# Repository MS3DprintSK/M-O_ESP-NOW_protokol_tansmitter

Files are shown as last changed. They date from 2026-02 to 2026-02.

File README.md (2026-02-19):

# M-O_ESP-NOW_protokol_tansmitter
Here you will find all the information about my way of controlling M-O from the Wall-e story. Don't look for the 3D model of M-O here! You will find it in the WALL-E Builders Club community files.

# M-O Control ESP NOW – Sedláček 🤖

This project utilizes the **ESP NOW** protocol for wireless robot control. The system is divided into a **Controller (Transmitter), Head, Eyes, and Body units**.

---

## 📑 Project Overview

- **Control Protocol:** Uses ESP NOW where eye displays process data as numbers **1–7** and display images accordingly.  
- **Head Unit:** Processes up/down movement (**0–180** from joystick) and controls the beacon.  
- **Body Unit:** Controls driving direction, speed, head rotation, and plays sounds.  
- **Security:** Communication is locked to specific MAC addresses to prevent accidental control of different robots.  

📄 **Full Documentation:**  
See the detailed manual here → [instruction.pdf](instruction.pdf)

---

## 🛠️ Hardware & Wiring

Detailed wiring diagrams can be found on **page 4** of the documentation.

### 🔌 Robot Wiring Diagram

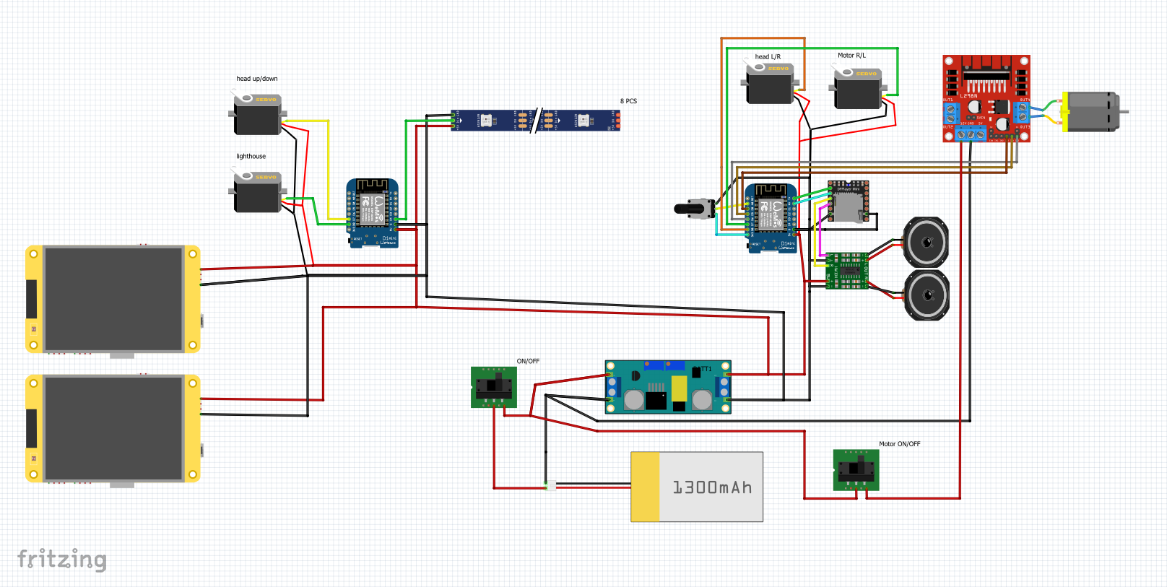
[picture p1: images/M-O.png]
Robot Wiring


### 🎮 Transmitter Wiring Diagram

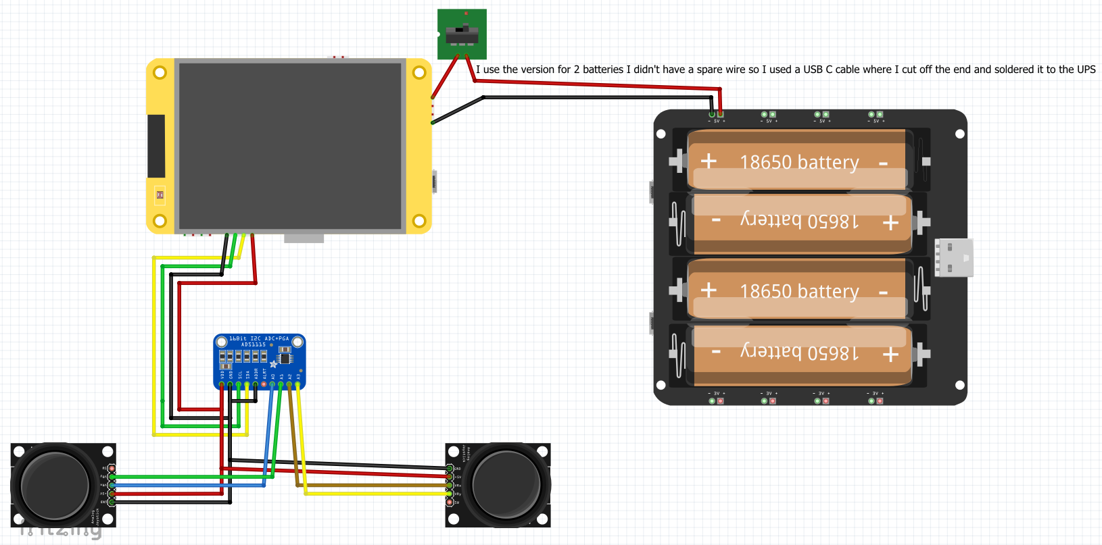
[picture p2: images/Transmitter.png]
Transmitter Wiring


---

## 📡 MAC Address Configuration

The first essential prerequisite is identifying the MAC addresses of all units.

### Identification
Use the **“MAC address code”** sketch to print the address to the Serial Monitor.

### Formatting

Rewrite addresses from:

A4:B0:0F:83:0C:8C

to:

0xA4, 0xB0, 0x0F, 0x83, 0x0C, 0x8C

### Implementation

- **Body & Head Code:** Replace the address on **line 7**  
- **Eyes Code:** Replace the address on **line 12**  
- **Transmitter Code:** Enter the MAC addresses of all other ESPs into **lines 30–33**

Detailed steps are on **page 1** of the manual → [instruction.pdf](instruction.pdf)

---

## 💻 Software Setup & Libraries

To ensure library compatibility, you must use these specific versions:

- **ESP32 Board Core:** 3.3.7  
- **TFT_eSPI:** 2.5.43  
- **Tjpg_Decoder:** 1.1.0  
- **SD:** 1.3.0  

> **Note:** Select **ESP32 Dev Module** when uploading.  
> The provided configuration file must be added to the `TFT_eSPI-master` library.

---

## 📂 SD Card & Multimedia

- **Images:** Upload images directly to the **root directory** (do not use folders).  
- **Sounds:** Rename files **0001 – 0050** and place them in a folder named `mp3`.  

**Eye Rotation (line 75):**

```cpp
tft.setRotation(3);
```

- Use **1** for the right eye  
- Use **3** for the left eye

---

## 💡 Tips and Observations

- **Weight Management:** Do not 3D print the head too heavy; use a maximum of **2 perimeters** to prevent the robot from tipping over.  
- **Safety / Demo Mode:** A power switch for the motor driver allows children to control eyes/sounds without the robot moving.  
- **Wiring:** Use the connector where **RX and TX** are located for **5V input** (**Do not connect the RX and TX pins!**)  

More observations are available in the manual → [instruction.pdf](instruction.pdf)

---

## 👤 Author

**MS3DprintSK (Sedláček)**
This work is licensed under a CC BY-NC 4.0 License. Attribution to MS3DprintSK (Sedláček) is required.

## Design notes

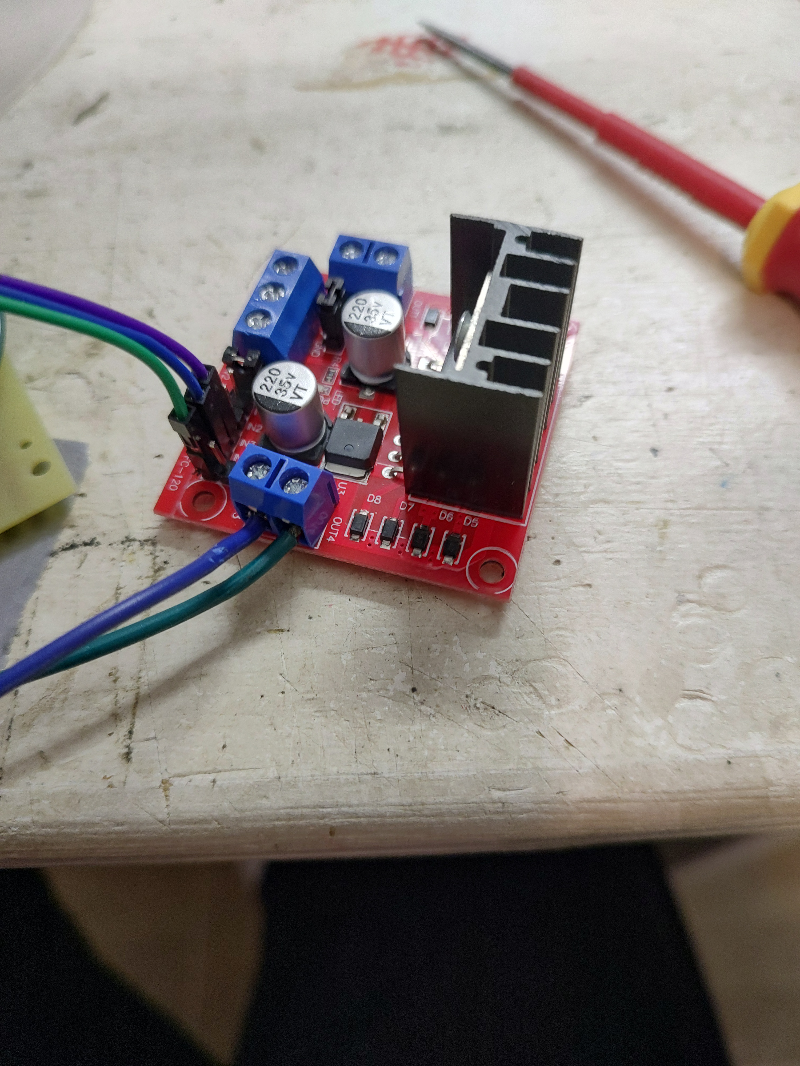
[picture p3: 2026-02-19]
Photos/IMG_20260215_202537132_HDR.jpg

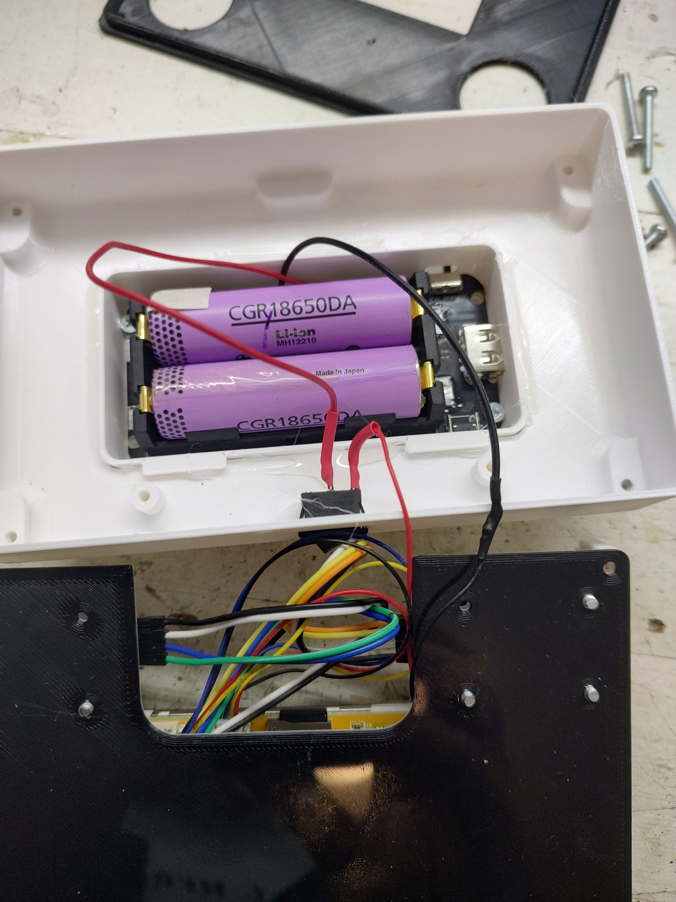
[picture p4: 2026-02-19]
Photos/IMG_20260217_163226008_HDR.jpg

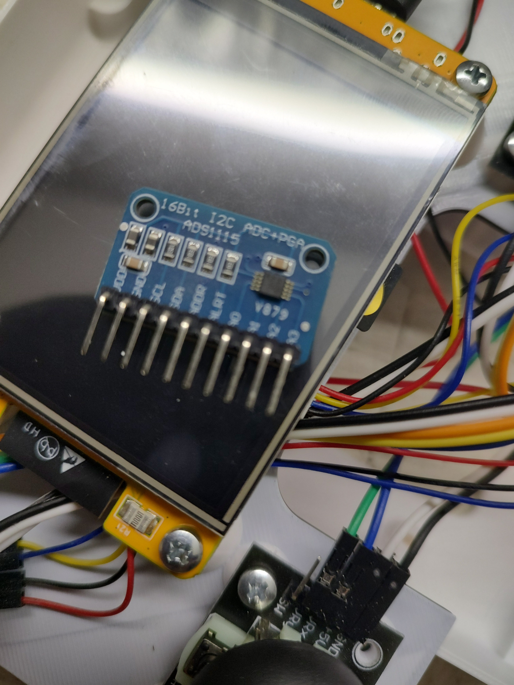
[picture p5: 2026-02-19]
Photos/IMG_20260217_153519624_HDR.jpg

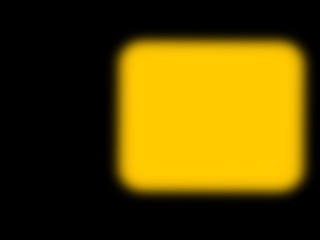
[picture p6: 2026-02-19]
eyes jpg/R/6. right.jpg

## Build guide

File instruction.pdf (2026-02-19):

M-O Control ESP NAW – Sedláček

I use the ESP NAW protocol for control. The eye displays process their portion of data as numbers 1-7 and display an image accordingly. The board in the head processes up/down movement (0-180 from the joystick) and controls the beacon based on the received number (1-7). The board in the body controls the driving direction, speed, head rotation, and plays sounds.

I am attaching the Fritzing files, where the wiring can be seen more clearly.

The first essential prerequisite for communication is identifying the MAC addresses of all ESP32 and ESP8266 units. The attached files contain Arduino sketches named "MAC address code" which will print the MAC address to the Serial Monitor. Make sure to write these addresses down! You will need them later in your code.

For the "Eyes" and the ESPs controlling the "Head" and "Body," you will need to record the MAC address of the Controller. Conversely, you must program the MAC addresses of the Eyes, Body, and Head into the Controller. This acts as a security feature to prevent accidental control of a different robot.

The obtained MAC addresses follow a structure similar to this example:

A4:B0:0F:83:0C:8C

You must rewrite them into the following format:

0xA4, 0xB0, 0x0F, 0x83, 0x0C, 0x8C

Instructions for implementation:

- Body Code: Find line 7 and replace {0xFF, 0xFF, 0xFF, 0xFF, 0xFF, 0xFF} with
your specific MAC address.
- Head Code: Follow the same step on line 7.
- Eyes Code: Follow the same step on line 12.
- Transmitter (Controller) Code: We will do the same here by recording the MAC addresses of all other ESPs. Enter the required MAC addresses into lines 30–33.

For the eyes and the controller, I used this display: ESP32-2432S028R You will need 3 units ESP32-2432S028R.
https://www.aliexpress.com/item/1005007730940177.html?spm=a2g0o.order_list.order_list_main.40.dc5c1802RcEPQo (https://www.aliexpress.com/item/1005007730940177.html) (ESP32 for Arduino LVGL WIFI&Bluetooth Development Board 2.8 240*320 Smart Display Screen 2.8inch LCD TFT Module With Touch WROOM)

Note: These displays use two different drivers... this specific one uses the less common one. I am attaching the configuration file, which must be added to the TFT_eSPI-master library.

I won’t list all the libraries here, but a few details are essential:

- When uploading, select ESP32 Dev Module. (Guides on how to add ESP32 and ESP8266 boards can be found online).
- To ensure library compatibility, you must use these specific versions:
- ESP32 Board Core: version 3.3.7
- TFT_eSPI: version 2.5.43
- Tjpg_Decoder: 1.1.0
- SD: 1.3.0

I had to fine-tune the colors and image orientation. Gemini AI was a huge help here, as there were issues with the User_Setup.h settings and the display driver version (due to inconsistent manufacturing across different vendors).

Wiring and Setup

- Powering the Eyes: I use the included cable. On my prototype board, I created a lead for 5V and GND. I used the connector where RX and TX are located—this is a 5V input; other pins run on 3.3V! Do not connect the RX and TX pins
- SD Card: Upload the images from the folder directly to the SD card. The images are different for the right and left eyes. Do not use folders—place them in the root directory.
- Code Adjustment: The code for both eyes is identical except for line 75: tft.setRotation(3); // 1 for the right eye or 3 for the left eye (or vice versa? :) )
- Transmitter: Follow the same process—upload the corresponding image files to the SD card and upload the Arduino code. I set the display orientation so the SD card faces me (there is more space inside the controller enclosure that way).
- Testing: I am attaching a file for touch testing called „testdotyku“.
- Joysticks: Connected via I2C using the ADS1115 (approx. €2). To connect the ADS1115 to the ESP32-2432S028R, I used the included wire and pins 22 and 27 (I2C bus).
- Battery Power: Since I didn't have an extra cable for the battery connector, I cut the end off a USB to USB-C cable and powered the board via the USB-C port. (See photos).

Body and Sound System

I am using two ESP8266 Wemos D1 mini Pro boards—one in the head and one in the body. I built custom PCBs for both using prototype perforated boards. Schematics are provided below.

- Audio: I use a DFPlayer Mini MP3 player (approx. €3) and a mini amplifier (PAM8403).

- Sounds: I used the original sounds from the manual, but renamed them as required by the MP3 player (0001 – 0050).

Warning: These must be in a folder named mp3 on the SD card. (Yes, the files aren't actually MP3s, but once I made that mistake, I didn't want to go back and fix it... SORRY).

- Volume: Controlled via a potentiometer.
- Beacon: The beacon in the head consists of an RGB LED strip (5V, 8 LEDs) left over from an old project. Tips and Observations
- I chose this solution to minimize wiring between the body and the head—only 2 wires (GND and 5V) are needed.
- Weight: Do not 3D print the head too heavy; use a maximum of 2 perimeters. I printed mine with solid walls—a big mistake—the head is too heavy, and the robot tips over. It helped that the head rotates into the direction of travel. Also, I reduced the maximum speed when the robot turns left or right.
- Mounting: I used Velcro to attach all components inside the robot.
- Stability: I placed the battery in the lower blue rear cover to keep the center of gravity low. I use a 3S LiPo.
- Safety/Demo Mode: I added a power switch for the motor driver. This allows children to "control" the robot (eyes/sounds) without it actually moving— perfect for tabletop presentations.
- Future Tweak: I might add some weight to the arms for better balance.

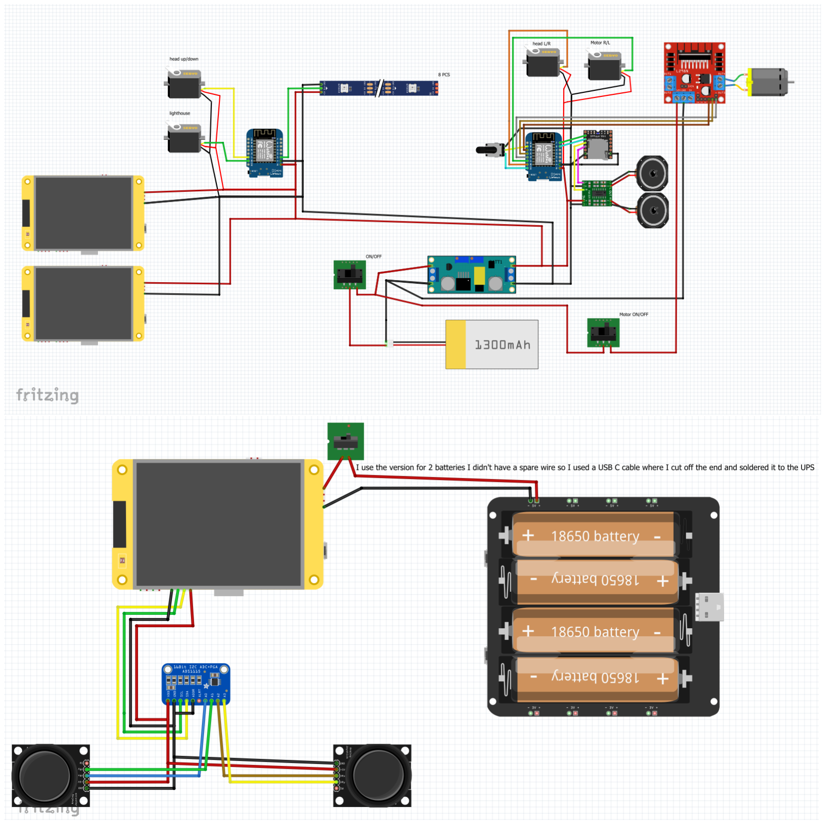
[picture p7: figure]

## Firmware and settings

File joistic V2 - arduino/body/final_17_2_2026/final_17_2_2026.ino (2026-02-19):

#include <ESP8266WiFi.h>
#include <espnow.h>
#include <Servo.h>
#include "DFRobotDFPlayerMini.h"

// --- ALLOWED MAC ADDRESS CONFIGURATION ---
uint8_t allowedMacAddress[] = {0xFF, 0xFF, 0xFF, 0xFF, 0xFF, 0xFF};

// --- PIN CONFIGURATION ---
#define PIN_HEAD_SERVO      D8
#define PIN_STEERING_SERVO  D7
#define PIN_MOTOR_PWM       D6
#define PIN_MOTOR_IN1       D5
#define PIN_MOTOR_IN2       D0
#define PIN_POTENTIOMETER   A0

// --- CONSTANTS AND SETTINGS ---
const int HEAD_OFFSET = -5;      
const int STEERING_OFFSET = 20;   
const int HEAD_DEADZONE = 15;   
const int MOTOR_DEADZONE = 8;    
const int MAX_SPEED = 800;    
const int QUARTER_SPEED = 200; 
const int STEERING_ANGLE = 30;    
int lastVolumeVal = -1;

Servo headServo;
Servo steeringServo;
DFRobotDFPlayerMini myDFPlayer;

typedef struct struct_message {
    int id;
    int joy[4]; 
} struct_message;

struct_message incomingData;
int lastHeadPos = 90 + HEAD_OFFSET;
int lastReceivedID = -1;
int previousID = -1;

bool isShakingActive = false;
bool waitForLoop = false;
bool isSequence7Active = false;
bool isSequence3Active = false;
bool isSequence2Active = false;

unsigned long lastShakeTime = 0;
unsigned long lastLoopTime = 0;
unsigned long sequenceChangeTime = 0;
unsigned long sequence3Time = 0;
unsigned long sequence2Time = 0;

int shakeCount = 0;
int shakeDirection = 1; 
int sequence7Step = 0;
const int sequence7Tracks[] = {9, 11, 13, 16};

// --- FUNCTIONS ---

void updateVolume() {
    int rawA0 = analogRead(PIN_POTENTIOMETER);
    int newVolume = map(rawA0, 0, 1023, 0, 30);
    if (abs(newVolume - lastVolumeVal) > 1) {
        myDFPlayer.volume(newVolume);
        lastVolumeVal = newVolume;
    }
}

void processMovement() {
    int rawHead = incomingData.joy[0];      // Head joystick
    int rawSteering = incomingData.joy[2];   // Steering joystick
    
    // 1. Steering Logic (Inverted mapping, 30-degree limit)
    bool isTurning = abs(rawSteering - 90) > 5;
    int finalSteering = (!isTurning) ? (90 + STEERING_OFFSET) : (map(rawSteering, 0, 180, 90 + STEERING_ANGLE, 90 - STEERING_ANGLE) + STEERING_OFFSET);
    steeringServo.write(constrain(finalSteering, 0, 180));

    // 2. Head Movement Logic (Combined manual control + automatic look-into-turn)
    if (!isShakingActive) {
        // Calculate deflection from center for both joysticks
        int headDiff = (abs(rawHead - 90) < HEAD_DEADZONE) ? 0 : (rawHead - 90);
        
        // Automatic head movement follows steering (inverted here too to match your inverted steering)
        int steeringDiff = (abs(rawSteering - 90) < 5) ? 0 : (90 - rawSteering); 
        
        // Combine both inputs + offset
        int finalHead = 90 + HEAD_OFFSET + headDiff + steeringDiff;
        
        if (abs(finalHead - lastHeadPos) > 1) {
            headServo.write(constrain(finalHead, 0, 180));
            lastHeadPos = finalHead;
        }
    }

    // 3. Throttle logic with speed reduction to QUARTER_SPEED during turns
    if (!isSequence3Active && !isSequence2Active) {
        int motorValue = incomingData.joy[3];
        int currentMaxLimit = isTurning ? QUARTER_SPEED : MAX_SPEED;

        if (motorValue > (90 + MOTOR_DEADZONE)) {
            digitalWrite(PIN_MOTOR_IN1, HIGH); digitalWrite(PIN_MOTOR_IN2, LOW);
            analogWrite(PIN_MOTOR_PWM, map(motorValue, 90 + MOTOR_DEADZONE, 180, 0, currentMaxLimit));
        } 
        else if (motorValue < (90 - MOTOR_DEADZONE)) {
            digitalWrite(PIN_MOTOR_IN1, LOW); digitalWrite(PIN_MOTOR_IN2, HIGH);
            analogWrite(PIN_MOTOR_PWM, map(motorValue, 90 - MOTOR_DEADZONE, 0, 0, currentMaxLimit));
        } 
        else {
            digitalWrite(PIN_MOTOR_IN1, LOW); digitalWrite(PIN_MOTOR_IN2, LOW);
            analogWrite(PIN_MOTOR_PWM, 0);
        }
    }
}

void updateEffects() {
    unsigned long currentTime = millis();
    if (isShakingActive) {
        if (currentTime - lastShakeTime >= 150) { 
            lastShakeTime = currentTime;
            int center = 90 + HEAD_OFFSET;
            if (shakeDirection == 1) { headServo.write(center + 15); shakeDirection = -1; }
            else { headServo.write(center - 15); shakeDirection = 1; shakeCount++; }
            if (shakeCount >= 10) { isShakingActive = false; headServo.write(center); waitForLoop = true; lastLoopTime = currentTime; }
        }
    }
    
    if (waitForLoop && (incomingData.id == 5 || incomingData.id == 6)) {
        if (currentTime - lastLoopTime >= 4000) { myDFPlayer.playMp3Folder(7); lastLoopTime = currentTime; }
    }
    
    if (isSequence7Active && incomingData.id == 7) {
        if (currentTime - sequenceChangeTime >= 3000) {
            sequence7Step++;
            if (sequence7Step < 4) { myDFPlayer.playMp3Folder(sequence7Tracks[sequence7Step]); sequenceChangeTime = currentTime; }
            else { isSequence7Active = false; }
        }
    }
    
    if (isSequence3Active && incomingData.id == 3) {
        unsigned long elapsed = currentTime - sequence3Time;
        if (elapsed < 1000) { digitalWrite(PIN_MOTOR_IN1, HIGH); digitalWrite(PIN_MOTOR_IN2, LOW); analogWrite(PIN_MOTOR_PWM, QUARTER_SPEED); }
        else if (elapsed < 2000) { digitalWrite(PIN_MOTOR_IN1, LOW); digitalWrite(PIN_MOTOR_IN2, HIGH); analogWrite(PIN_MOTOR_PWM, QUARTER_SPEED); }
        else { digitalWrite(PIN_MOTOR_IN1, LOW); digitalWrite(PIN_MOTOR_IN2, LOW); analogWrite(PIN_MOTOR_PWM, 0); isSequence3Active = false; }
    }
    
    if (isSequence2Active && incomingData.id == 2) {
        if (currentTime - sequence2Time < 500) {
            digitalWrite(PIN_MOTOR_IN1, LOW); digitalWrite(PIN_MOTOR_IN2, HIGH);
            analogWrite(PIN_MOTOR_PWM, QUARTER_SPEED);
        } else {
            digitalWrite(PIN_MOTOR_IN1, LOW); digitalWrite(PIN_MOTOR_IN2, LOW);
            analogWrite(PIN_MOTOR_PWM, 0);
            isSequence2Active = false;
        }
    }
}

void OnDataRecv(uint8_t * mac, uint8_t *data, uint8_t len) {
    for (int i = 0; i < 6; i++) {
        if (mac[i] != allowedMacAddress[i]) return; 
    }

    memcpy(&incomingData, data, sizeof(incomingData));

    if (incomingData.id != lastReceivedID) {
        previousID = lastReceivedID;
        myDFPlayer.stop();
        
        isShakingActive = false; waitForLoop = false; 
        isSequence7Active = false; isSequence3Active = false; isSequence2Active = false;

        if (incomingData.id == 1) {
            if (previousID == 5 || previousID == 6) {
                myDFPlayer.playMp3Folder(21);
            } else {
                myDFPlayer.playMp3Folder(1); 
            }
        }
        else if (incomingData.id == 2) {
            myDFPlayer.playMp3Folder(8); isSequence2Active = true; sequence2Time = millis();
        }
        else if (incomingData.id == 3) {
            myDFPlayer.playMp3Folder(57); isSequence3Active = true; sequence3Time = millis();
        }
        else if (incomingData.id == 4) {
            myDFPlayer.playMp3Folder(27);
        }
        else if (incomingData.id == 5) {
            myDFPlayer.playMp3Folder(4); isShakingActive = true; shakeCount = 0; shakeDirection = 1; lastShakeTime = millis();
        }
        else if (incomingData.id == 6) {
            myDFPlayer.playMp3Folder(10); waitForLoop = true; lastLoopTime = millis();
        }
        else if (incomingData.id == 7) {
            sequence7Step = 0; isSequence7Active = true; myDFPlayer.playMp3Folder(sequence7Tracks[0]); sequenceChangeTime = millis();
        }

        lastReceivedID = incomingData.id;
    }
}

void setup() {
    Serial.begin(9600); 
    headServo.write(90 + HEAD_OFFSET);
    steeringServo.write(90 + STEERING_OFFSET);
    headServo.attach(PIN_HEAD_SERVO);
    steeringServo.attach(PIN_STEERING_SERVO);
    
    pinMode(PIN_MOTOR_IN1, OUTPUT); pinMode(PIN_MOTOR_IN2, OUTPUT); pinMode(PIN_MOTOR_PWM, OUTPUT);

    if (myDFPlayer.begin(Serial)) {
        int initVol = map(analogRead(PIN_POTENTIOMETER), 0, 1023, 0, 30);
        myDFPlayer.volume(initVol);
        lastVolumeVal = initVol;
    }

    WiFi.mode(WIFI_STA); WiFi.disconnect();
    if (esp_now_init() == 0) {
        esp_now_set_self_role(ESP_NOW_ROLE_SLAVE);
        esp_now_register_recv_cb(OnDataRecv);
    }

    delay(2000);
    myDFPlayer.playMp3Folder(1); 
    incomingData.id = 0; 
}

void loop() {
    updateVolume(); 
    processMovement();         
    updateEffects();
    yield();
}

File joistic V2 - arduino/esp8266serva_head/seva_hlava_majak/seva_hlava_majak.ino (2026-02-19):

#include <ESP8266WiFi.h>
#include <espnow.h>
#include <Servo.h>
#include <NeoPixelBus.h>

// --- ALLOWED MAC ADDRESS CONFIGURATION ---
uint8_t allowedMacAddress[] = {0xFF, 0xFF, 0xFF, 0xFF, 0xFF, 0xFF};

// --- PIN CONFIGURATION ---
#define PIN_BEACON_SERVO D8
#define PIN_SERVO_Y      D7
const uint16_t LedCount = 8; 

// NeoPixel setup (Data wire must be on pin D4 / GPIO2)
NeoPixelBus<NeoGrbFeature, NeoEsp8266Uart1800KbpsMethod> strip(LedCount);

RgbColor red(255, 0, 0);
RgbColor black(0, 0, 0);

// --- BEACON ANIMATION VARIABLES ---
const uint8_t pairs[4][2] = { {0, 4}, {1, 5}, {2, 6}, {3, 7} };
uint8_t currentPair = 0;
uint8_t nextPair    = 1;
uint8_t fade        = 0;
bool fadingIn       = true;
uint16_t rotationSpeed = 10; 
uint8_t fadeStep       = 15;
unsigned long lastUpdate = 0;

// --- SERVO SETTINGS ---
Servo beaconServo;
Servo servoY;
const int BEACON_MIN = 0;
const int BEACON_MAX = 165;
bool isBeaconExtended = false; 
const int Y_OFFSET = 60; // Offset for head lift
const int Y_LIMIT_MIN = 120; // Minimum safe head angle

// --- DATA STRUCTURE ---
typedef struct struct_message {
    int id;
    int joy[4];
} struct_message;

struct_message incomingData;

// --- DATA RECEIVE FUNCTION WITH MAC FILTER ---
void OnDataRecv(uint8_t * mac, uint8_t *data, uint8_t len) {
  // 1. Check if data comes from the allowed MAC address
  for (int i = 0; i < 6; i++) {
    if (mac[i] != allowedMacAddress[i]) {
      return; // Ignore unknown devices
    }
  }

  // 2. Copy received data
  memcpy(&incomingData, data, sizeof(incomingData));
  
  // 3. Beacon logic (extension based on ID)
  bool shouldBeExtended = (incomingData.id == 5 || incomingData.id == 6 || incomingData.id == 7);
  if (shouldBeExtended != isBeaconExtended) {
      if (shouldBeExtended) {
          beaconServo.write(BEACON_MAX);
      } else {
          beaconServo.write(BEACON_MIN);
          // Turn off LEDs when retracted
          for(int i=0; i<LedCount; i++) strip.SetPixelColor(i, black);
          strip.Show();
      }
      isBeaconExtended = shouldBeExtended;
  }

  // 4. Servo Y logic with limit 120
  int invertedY = 180 - incomingData.joy[1];
  int finalY = constrain(invertedY + Y_OFFSET, Y_LIMIT_MIN, 180); 
  servoY.write(finalY);
}

void setup() {
  Serial.begin(115200);

  // Initialize LED strip
  strip.Begin();
  strip.Show(); 
  
  // Initialize servos
  beaconServo.attach(PIN_BEACON_SERVO, 650, 2600);
  servoY.attach(PIN_SERVO_Y);
  
  // Initial positions (with limits applied)
  beaconServo.write(BEACON_MIN);
  servoY.write(constrain(90 + Y_OFFSET, Y_LIMIT_MIN, 180));

  // Initialize WiFi and ESP-NOW
  WiFi.mode(WIFI_STA);
  WiFi.disconnect();
  
  if (esp_now_init() != 0) {
    Serial.println("Error initializing ESP-NOW");
    return;
  }
  
  esp_now_set_self_role(ESP_NOW_ROLE_COMBO);
  esp_now_register_recv_cb(OnDataRecv);
}

// --- LED ANIMATION (BEACON) ---
void animateBeacon() {
  unsigned long now = millis();
  if (now - lastUpdate >= rotationSpeed) {
    lastUpdate = now;

    if (fadingIn) {
      if (fade < 255 - fadeStep) fade += fadeStep;
      else fadingIn = false;
    } else {
      if (fade > fadeStep) fade -= fadeStep;
      else {
        currentPair = nextPair;
        nextPair = (nextPair + 1) % 4;
        fade = 255;
        fadingIn = false;
      }
    }
    
    // Clear and draw new LED pair
    for(int i=0; i<LedCount; i++) strip.SetPixelColor(i, black);

    if (fadingIn) {
      RgbColor c = RgbColor(fade, 0, 0);
      strip.SetPixelColor(pairs[currentPair][0], c);
      strip.SetPixelColor(pairs[currentPair][1], c);
    } else {
      RgbColor c1 = RgbColor(fade, 0, 0);
      RgbColor c2 = RgbColor(255 - fade, 0, 0);
      strip.SetPixelColor(pairs[currentPair][0], c1);
      strip.SetPixelColor(pairs[currentPair][1], c1);
      strip.SetPixelColor(pairs[nextPair][0], c2);
      strip.SetPixelColor(pairs[nextPair][1], c2);
    }
    strip.Show();
  }
}

void loop() {
  // Animation runs only if the beacon is mechanically extended
  if (isBeaconExtended) {
    animateBeacon();
  }
  yield(); // Maintain WiFi stack stability
}
